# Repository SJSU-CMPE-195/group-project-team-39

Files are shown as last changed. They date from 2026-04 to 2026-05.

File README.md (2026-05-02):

# RoboMallet

Source code for the ROBOTMALLET robotic system's control logic.

## Team

| Name | GitHub | Email |
| --- | --- | --- |
| Kenny Tran | [@ktran1121](https://github.com/ktran1121) | kenny.k.tran@sjsu.edu |
| Kshitij Shirule | [@K-Shirule](https://github.com/K-Shirule) | kshitij.shirule@sjsu.edu |
| Nam Nguyen | [@namng2](https://github.com/namng2) | nam.h.nguyen04@sjsu.edu  |
| Yathien Thai | [@yyaatt0](https://github.com/yyaatt0) | yathien.thai@sjsu.edu |

**Advisor:** [Dr. Wencen Wu]

## Prerequisites

- [Docker Desktop](https://www.docker.com/products/docker-desktop/) installed and running
- A Docker Hub account (required to build and push container images)
- Docker Buildx enabled (included by default in Docker Desktop)
- SSH or terminal access to the target MCU/board ([PuTTY](https://www.putty.org/) recommended for Windows users)

## Installation

1. Clone the repository:

   ```bash
   git clone https://github.com/<your-org>/RoboMallet.git
   cd RoboMallet
   ```

2. Log in to your Docker Hub account:

   ```bash
   docker login -u yathien
   ```

3. Build and push the C++ service container:

   ```bash
   docker buildx build --platform linux/arm64 -t yathien/cppsvc:dev --push ./cppsvc
   ```

4. Build and push the Python service container:

   ```bash
   docker buildx build --platform linux/arm64 -t yathien/pysvc:dev --push ./pysvc
   ```

## Configuration

Before running the application, ensure the following hardware is connected to the MCU:

- Motor drivers (iSV57T) wired to the appropriate GPIO pins for DIR and PUL signals
- Limit switches wired to the designated GPIO input pins
- All power supplies are connected and within operating voltage range

Refer to the Ixora carrier board datasheet and the pin mapping in the project documentation for exact GPIO assignments.

## Running the Application

SSH into the target board and run:

```bash
cd ~/RoboMallet
docker compose pull
docker compose up -d
```

To view logs:

```bash
docker compose logs -f
```

To stop the application:

```bash
docker compose down
```

## Usage

Once the containers are running, the robotic system will initialize the motor drivers and limit switches on startup. The system listens for commands to control mallet rotation and positioning.

## Project Structure

```
RoboMallet/
├── cppsvc/                 # C++ service (motor control, GPIO interface)
│   ├── include/            # Header files (.hpp)
│   ├── src/                # Source files (.cpp)
│   ├── main.cpp            # Entry point
│   ├── Dockerfile          # ARM64 container build
│   └── CMakeLists.txt      # Build configuration
├── pysvc/                  # Python service
│   ├── Dockerfile          # ARM64 container build
│   └── main.py             # Entry point
├── docker-compose.yml      # Multi-container orchestration
└── README.md
```

## Stress Test Results

### Test Configuration
- Testing Type: Playing against robot for stress testing  
- Duration: 10-15 minutes per trial  
- Input Method: Manual puck shots (human player)  
- Scenarios Tested:
  - Straight shots at varying speeds  
  - Angled shots including wall bounces  
  - Rapid consecutive shots (high-frequency gameplay)  
- Environment:
  - Fixed overhead camera  
  - Controlled and Bright indoor lighting for easy color detection

---

### Results
| Metric | Value |
|---|---|
| Max Trackable Puck Speed | 0.813 m/s |
| Interception Success Rate | 93.5 % |
| Avg Response Time (vision → actuation) | 21 - 81 ms |
| Prediction Error (avg) | 15% |

---

### Observations
- System performs reliably for straight and angled shots  
- Performance decreases for high-speed, multi-bounce trajectories, and drift caused due to air
- Largest bottleneck is in the transferance of information from one process to the next using shared memory
- Occasional tracking loss observed during rapid consecutive shots

---

### Bottlenecks
- Camera frame rate and image processing latency  
- Mechanical limits of gantry speed and acceleration  

---

### Testing Approach

| Approach | Tool | Use Case |
|---|---|---|
| Manual Testing | Documented procedure | Simulate real gameplay with controlled shot variations |
| Vision Pipeline Testing | OpenCV (logging + profiling) | Measure detection latency and tracking accuracy using hardware timers and counters |
| Control System Testing | Motor controller + encoder feedback | Evaluate response time and positioning accuracy |
| Integrated System Testing | Full system | End-to-end performance under realistic game conditions |

## Demo

🎥 **Project Demo Videos**

- [CMPE195B RoboMallet Group39 Demo 1](https://youtu.be/watch?v=AesrC-o85-U)
- [CMPE195B RoboMallet Group39 Demo 2](https://youtu.be/WAsmsQb9nug)

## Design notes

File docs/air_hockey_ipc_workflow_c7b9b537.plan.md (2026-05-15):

---
name: Air Hockey IPC Workflow
overview: Integrate pysvc (object detection) and cppsvc (gantry control) via POSIX shared memory and semaphores, with a new trajectory predictor, coordinate mapper, and IPC handler classes on both sides. The workflow detects incoming pucks, predicts trajectories with bounce support, checks critical zone intersection, and sends movement commands to the gantry.
todos:
  - id: coord-mapper
    content: "Create pysvc/coordinate_mapper.py: CoordinateMapper class with configurable offsets, pixel<->gantry conversion"
    status: done-deviation
    note: "Folded into px_to_gantry_mm() in pysvc/main.py + constants in calibration_config.py. No separate class."
  - id: puck-detector
    content: "Create pysvc/puck_detector.py: PuckDetector class wrapping detection + tracking (green_mask_hsv, detect_green_puck_center, p0/p1 state, missing_count)"
    status: done-deviation
    note: "Detection lives in pysvc/green_puck_detect.py (functions, not a class). Kalman tracking + missing_count state is inline in pysvc/main.py."
  - id: trajectory-predictor
    content: "Create pysvc/trajectory_predictor.py: TrajectoryPredictor class with bounce-aware ray casting and critical zone intersection test"
    status: done-deviation
    note: "Implemented inline as trace_path_to_bottom() + first_border_intersection() in pysvc/main.py. Approach differs from plan: cast to bottom row and check predicted X (instead of per-segment ray-vs-rect)."
  - id: py-ipc
    content: "Create pysvc/ipc_handler.py: IPCHandler class using posix_ipc for shared memory + semaphores (send_command, read_status, close)"
    status: completed
  - id: cpp-ipc
    content: "Create cppsvc/include/ipc_handler.hpp + cppsvc/src/ipc_handler.cpp: AirHockeyIPC struct, IPCHandler class (read_command, write_status, wait_for_command)"
    status: completed
  - id: py-main
    content: "Modify pysvc/main.py: comment out old code, add new main loop integrating PuckDetector + TrajectoryPredictor + CoordinateMapper + IPCHandler"
    status: in-progress
    note: "Main loop, detection, tracking, and INTERCEPT/IDLE commands are wired. STILL-puck PUSH_NORTH / PUSH_OUT branches (workflow steps 3e Case 1 & 2) are NOT yet implemented."
  - id: cpp-main
    content: "Modify cppsvc/main.cpp: add IPC command loop (home -> default pos -> wait for command -> move_to_coord -> update status)"
    status: completed
  - id: cmake
    content: "Modify cppsvc/CMakeLists.txt: add ipc_handler.cpp source, link rt library"
    status: completed
  - id: push-emit
    content: "Wire PUSH_NORTH / PUSH_OUT two-step sequences into pysvc/main.py per workflow step 3e and Edge Cases 1 & 2 (position behind puck, wait ready=1, send target_y=901)."
    status: pending
    note: "Agreed BEHIND_OFFSET_MM = 80 (mallet r ~47.5mm + puck r ~30mm). If puck stops being STILL between step 1 and step 2, abort sequence and re-evaluate next tick."
  - id: low-light-hardening
    content: "Low-light robustness: CLAHE on V channel in green_mask_hsv(); Kalman processNoiseCov velocity terms lowered to 1e-3, measurementNoiseCov raised to 1e-1; dev HUD shows |v| and still_count under HEADLESS=0."
    status: completed
  - id: calib-assert
    content: "verify_gantry_calibration() in pysvc/main.py asserts GANTRY_TL_PX -> (0,901) mm and GANTRY_BR_PX -> (869,0) mm within CALIBRATION_TOL_MM (2.0). px_to_gantry_mm_raw() helper added so the clamp doesn't mask errors. crop_calibrate.py PREVIEW shows live implied mm with OK/BAD tags + loud warning on S-save."
    status: completed
    note: "Bypass via SKIP_CALIBRATION_CHECK=1 env var. Current calibration_config.py values FAIL the check (PX_PER_CM_X derived from 55cm CRIT zone vs GANTRY implying ~3.87 px/cm) -- rig re-calibration required."
  - id: corner-check
    content: "run_four_corner_check() in pysvc/main.py drives the gantry to SW(0,0), SE(869,0), NE(869,901), NW(0,901) via INTERCEPT, waits ready=1 with status_seq advance + 30s timeout per corner, prompts operator y/n/r, exits non-zero on any fail. Sends IDLE to park afterwards."
    status: completed
    note: "Bypass via SKIP_CORNER_CHECK=1 env var. Runs after IPC connect, before camera loop."
isProject: false
---

# Air Hockey IPC Workflow Plan

## Implementation status (snapshot)

This plan was written as the design doc for the pysvc ↔ cppsvc IPC integration.
Most of it is now built, with some deviations from the original architecture.
See per-todo `note:` fields in the frontmatter for specifics.

**Done:**

- IPC layer on both sides ([`pysvc/ipc_handler.py`](../pysvc/ipc_handler.py),
  [`cppsvc/include/ipc_handler.hpp`](../cppsvc/include/ipc_handler.hpp),
  [`cppsvc/src/ipc_handler.cpp`](../cppsvc/src/ipc_handler.cpp)).
- cppsvc command loop ([`cppsvc/main.cpp`](../cppsvc/main.cpp)): home → default
  pos → wait → `move_to_coord` → status update.
- CMake wiring (`ipc_handler.cpp` + `rt` link).
- pysvc main loop ([`pysvc/main.py`](../pysvc/main.py)): capture → TPS remap →
  Kalman detection → trajectory prediction → convergence buffer → INTERCEPT /
  IDLE commands.
- Low-light hardening: CLAHE V-channel normalisation in `green_mask_hsv()`,
  retuned Kalman covariance (`processNoiseCov` velocity terms = `1e-3`,
  `measurementNoiseCov` = `1e-1`), and a `HEADLESS=0` dev HUD showing
  `|v|` and `still_count`.
- Calibration verification: `verify_gantry_calibration()` asserts the
  GANTRY pixel-corner → mm mapping at pysvc startup;
  `run_four_corner_check()` drives the gantry to the four mm corners and
  prompts the operator to confirm each.  `SKIP_CALIBRATION_CHECK=1` and
  `SKIP_CORNER_CHECK=1` env vars bypass.  See
  [`docs/handoff.md`](handoff.md) → *Calibration verification* for the
  full design.

**Not yet built:**

- `PUSH_NORTH` / `PUSH_OUT` emit logic in pysvc (workflow step 3e, Cases 1 & 2).
  Defined in the IPC protocol and described in *Edge Case Handling* below,
  but `main.py` only emits `IDLE` and `INTERCEPT` today.

**Deviations from this plan:**

- No separate `CoordinateMapper`, `PuckDetector`, `TrajectoryPredictor`
  classes. The functionality is split between
  [`pysvc/green_puck_detect.py`](../pysvc/green_puck_detect.py) (HSV +
  centroid) and inline helpers in `main.py` (`px_to_gantry_mm`,
  `trace_path_to_bottom`, `first_border_intersection`). Calibration
  constants live in
  [`pysvc/calibration_config.py`](../pysvc/calibration_config.py) instead of
  being class fields.
- Trajectory prediction casts to the bottom row (robot side) and checks
  the predicted X against the critical-zone X-range, plus a convergence
  buffer for stability. The plan's per-segment ray-vs-rectangle test
  was not implemented — current approach is simpler and good enough for
  INTERCEPT, but it ignores trajectories that *enter* the critical zone
  laterally without reaching the bottom row.
- `pysvc/calibration_config.py` adds `PLAY_*_PX` and `GANTRY_*_PX` nested
  rectangles (a refinement not in the original plan) so `main.py` can
  branch on which region a STILL puck is in. See
  [`docs/handoff.md`](handoff.md) → *Camera physical coverage*.

For the canonical state-of-the-system overview, see
[`docs/handoff.md`](handoff.md).

---

## Coordinate System

Both services will use a **bottom-left origin** with X right, Y up:

- **Camera pixel space**: (0,0) at bottom-left, (640, 360) at top-right. OpenCV natively uses top-left origin, so all Y values are flipped via `y_cam = (h - 1) - y_opencv`.
- **Gantry space**: (0,0) at bottom-left (south-west, limit switch corner), (869, 901) mm at top-right. Already matches after homing.

### Pixel-to-Gantry Mapping ([`pysvc/coordinate_mapper.py`](pysvc/coordinate_mapper.py) -- new file)

The camera view physically covers a larger area than the gantry range, with configurable offsets:

```
Camera physical extent:
  width  = LEFT_OFFSET + GANTRY_X + RIGHT_OFFSET = 55 + 869 + 55 = 979 mm
  height = BOTTOM_OFFSET + GANTRY_Y + TOP_OFFSET  = 47 + 901 + 0  = 948 mm

Conversion (camera pixel -> gantry mm):
  x_mm = (pixel_x / CAM_WIDTH) * PHYS_WIDTH - LEFT_OFFSET
  y_mm = (pixel_y / CAM_HEIGHT) * PHYS_HEIGHT - BOTTOM_OFFSET

Valid gantry range: 0 <= x_mm <= 869, 0 <= y_mm <= 901
```

All offsets (`LEFT_OFFSET_MM`, `RIGHT_OFFSET_MM`, `BOTTOM_OFFSET_MM`, `TOP_OFFSET_MM`) and camera resolution (`CAM_WIDTH`, `CAM_HEIGHT`) are configurable constants.

The `CoordinateMapper` class provides:

- `pixel_to_gantry_mm(px, py) -> (x_mm, y_mm)` -- converts and returns raw mm (can be outside gantry range)
- `gantry_mm_to_pixel(x_mm, y_mm) -> (px, py)` -- inverse
- `is_in_gantry_range(x_mm, y_mm) -> bool` -- bounds check
- `clamp_to_gantry(x_mm, y_mm) -> (x_mm, y_mm)` -- clamp to nearest valid gantry position

---

## Critical Zone

Defined in **camera pixel space** (bottom-left origin) as a configurable rectangle. Default: full width, from Y=0 to `CRITICAL_ZONE_Y_MAX` (configurable, e.g. 180 px = bottom half). Any predicted trajectory that enters this rectangle triggers a gantry INTERCEPT command.

---

## Files (as built)

The architecture in *Implementation status* above differs from the original
plan (no separate detector / predictor / mapper classes).  Below is what
actually got built.

### pysvc (Python) — created

| File | Status | Purpose |
| ---- | --- | --- |
| [`pysvc/ipc_handler.py`](../pysvc/ipc_handler.py) | done | `IPCHandler` class: posix_ipc shared memory + semaphores (`send_command`, `read_status`, `close`). |
| [`pysvc/green_puck_detect.py`](../pysvc/green_puck_detect.py) | done | `green_mask_hsv()` (CLAHE + HSV inRange + morph) and `detect_green_puck_center()` (contour centroid). Replaces the planned `PuckDetector` class. |
| [`pysvc/vision_preprocess.py`](../pysvc/vision_preprocess.py) | done | `build_remap_maps()` (TPS RBF) + `preprocess_frame()` (remap → 90-CW rotate). Shared by `main.py`, `test_detection.py`, `crop_calibrate.py`. |
| [`pysvc/calibration_config.py`](../pysvc/calibration_config.py)| done | Single source for `OUTPUT_W/H`, `SRC_POINTS`, `MALLET_ORIGIN_PX`, `PLAY/GANTRY/CRIT` nested rectangles, `PX_PER_CM_X/Y`. Replaces the planned `CoordinateMapper` configurable constants. |
| [`pysvc/camera.py`](../pysvc/camera.py) | done | `StereoCamera` wrapper around V4L2 + per-pixel stereo fusion. |
| [`pysvc/crop_calibrate.py`](../pysvc/crop_calibrate.py) | done | One-time GUI tool: drag TPS handles + PLAY/GANTRY/CRIT/MALLET handles, prints config block on **S**. |
| [`pysvc/test_detection.py`](../pysvc/test_detection.py) | done | Visual detector test (no IPC, no Kalman). Same remap + HSV path as `main.py`. |

### pysvc (Python) — NOT created (folded inline)

| Planned file | Where it lives now |
| --- | --- |
| `pysvc/puck_detector.py` (PuckDetector class) | Detection in `green_puck_detect.py`; Kalman + tracking state inline in `main.py`. |
| `pysvc/trajectory_predictor.py` (TrajectoryPredictor) | `trace_path_to_bottom()` + `first_border_intersection()` inline in `main.py`. |
| `pysvc/coordinate_mapper.py` (CoordinateMapper class) | `px_to_gantry_mm()` inline in `main.py`; constants in `calibration_config.py`. |

### cppsvc (C++) — created

| File | Status | Purpose |
| ---- | --- | --- |
| [`cppsvc/include/ipc_handler.hpp`](../cppsvc/include/ipc_handler.hpp) | done | `IPCHandler` class header + `AirHockeyIPC` struct + `static_assert(sizeof == 32)`. |
| [`cppsvc/src/ipc_handler.cpp`](../cppsvc/src/ipc_handler.cpp) | done | shm_open + sem_open setup, read commands, write status. |

### Modified files

| File | Status |
| ---- | --- |
| [`pysvc/main.py`](../pysvc/main.py) | Capture → TPS remap → Kalman detection → trajectory → convergence-based commit → INTERCEPT / IDLE. PUSH branches still pending. |
| [`cppsvc/main.cpp`](../cppsvc/main.cpp) | done — home → default pos → wait for command → `move_to_coord` → status update. |
| [`cppsvc/CMakeLists.txt`](../cppsvc/CMakeLists.txt) | done — `ipc_handler.cpp` added, `rt` linked. |

`objectdetect_and_trajectory.py` and `object_detect_Apalis.py` remain as-is (legacy reference).

---

## Shared Memory Layout

Named shared memory: `/airhockey_shm`

```
struct AirHockeyIPC {
    // Command (pysvc -> cppsvc)
    float    target_x_mm;     // gantry target X
    float    target_y_mm;     // gantry target Y
    uint8_t  command;          // IDLE=0, INTERCEPT=1, PUSH_NORTH=2, PUSH_OUT=3
    uint8_t  priority;         // LOW=0, MEDIUM=1, HIGH=2
    uint16_t _pad1;
    uint32_t command_seq;      // incremented per new command

    // Status (cppsvc -> pysvc)
    float    current_x_mm;    // current mallet X
    float    current_y_mm;    // current mallet Y
    uint8_t  state;            // IDLE=0, MOVING=1, HOMING=2, ERROR=3
    uint8_t  ready;            // 1 = ready for next command
    uint16_t _pad2;
    uint32_t status_seq;       // incremented per status update
};
// Total: 32 bytes, naturally aligned
```

Priority mapping: INTERCEPT=HIGH(2), PUSH_NORTH=MEDIUM(1), PUSH_OUT=MEDIUM(1), IDLE=LOW(0).

---

## Semaphore Protocol

Two named POSIX semaphores:

- **`/airhockey_mutex`** (binary, init=1): Protects shared memory reads/writes.
- **`/airhockey_cmd`** (counting, init=0): Signals cppsvc that a new command is available.

### Write sequence (pysvc):

1. `sem_wait(mutex)` -- acquire lock
2. Write command fields to shared memory, increment `command_seq`
3. `sem_post(mutex)` -- release lock
4. `sem_post(cmd)` -- signal cppsvc

### Read sequence (cppsvc):

1. `sem_wait(cmd)` -- block until command available
2. `sem_wait(mutex)` -- acquire lock
3. Read command fields, copy locally
4. `sem_post(mutex)` -- release lock
5. Execute movement

### Status update (cppsvc):

1. `sem_wait(mutex)` -- acquire lock
2. Write status fields, increment `status_seq`
3. `sem_post(mutex)` -- release lock

### Status read (pysvc):

1. `sem_wait(mutex)` -- acquire lock
2. Read status fields
3. `sem_post(mutex)` -- release lock

---

## Workflow: pysvc Main Loop

```
1. Initialize: PuckDetector, TrajectoryPredictor, CoordinateMapper, IPCHandler
2. Open camera (configurable resolution/fps)
3. Loop:
   a. Read frame
   b. puck_state = detector.update(frame)   # returns position, velocity, is_still, is_detected
   c. Flip Y for bottom-left origin
   d. If NOT detected:
        - Send IDLE command (gantry returns to default position)
        - continue
   e. If puck is STILL:
        - Convert puck position to gantry mm
        - Case 1: Puck is on the side, outside gantry X range (x_mm < 0 or x_mm > 869)
            -> Send PUSH_NORTH: target_x = clamp(x_mm, 0, 869), target_y = 901 (push to top)
        - Case 2: Puck is within gantry range but outside critical zone
            -> Send PUSH_OUT: target = position behind puck, then push north
        - Case 3: Puck is in critical zone (do nothing special, it's on our side and still)
            -> Send IDLE or hold position
   f. If puck is MOVING:
        - predicted_pt = trajectory.predict(puck_pos, velocity, camera_bounds)
          (handles side-wall bounces, returns predicted endpoint)
        - Check if predicted trajectory intersects critical zone
        - If YES:
            -> Convert intersection point to gantry mm
            -> Clamp to gantry range
            -> Send INTERCEPT command (priority=HIGH)
        - If NO:
            -> Send IDLE (puck heading away from us)
   g. Read cppsvc status for logging/monitoring
```

---

## Workflow: cppsvc Main Loop

```
1. Initialize: gantry (motors, switches), IPCHandler
2. Home gantry: move_to_origin()
3. Move to default position: move_to_coord(434, 0)  // center-bottom
4. Update status: state=IDLE, ready=1
5. Loop:
   a. Wait for command (sem_wait on /airhockey_cmd)
   b. Read command from shared memory
   c. Update status: state=MOVING, ready=0
   d. Execute: move_to_coord(target_x_mm, target_y_mm)
   e. Update status: current_x/y = new position, state=IDLE, ready=1
   f. Loop back to (a)
```

For PUSH commands, the gantry moves to the target position which is pre-calculated by pysvc to be "behind" the puck, then pysvc sends a follow-up coordinate to push through.

---

## Edge Case Handling

### Edge Case 1: Puck at rest on the side, outside gantry X range

The puck is in the 5.5cm offset zone (camera sees it, but gantry can't reach its exact X). The mallet moves to the nearest gantry edge at the puck's Y coordinate minus an offset (to get "behind" it), then pushes north. Since the mallet is at the gantry edge and the puck is just outside, the mallet "rubs against the side" of the puck, pushing it northward out of the camera view.

**pysvc logic:**

1. Detect puck is still and `x_mm < 0` or `x_mm > 869`
2. Set `target_x = 0` (if puck on left side) or `target_x = 869` (if puck on right side)
3. Set `target_y = puck_y_mm - BEHIND_OFFSET` (position behind/south of puck)
4. Send PUSH_NORTH command
5. After gantry reports ready, send follow-up with `target_y = 901` (push north to max)

### Edge Case 2: Puck at rest outside critical zone, within gantry range

The puck is reachable by the gantry but not in the critical zone (it's in the upper portion of the field). Push it north out of the camera view.

**pysvc logic:**

1. Detect puck is still and within gantry range but Y > critical zone top
2. Set `target_x = puck_x_mm`, `target_y = puck_y_mm - BEHIND_OFFSET`
3. Send PUSH_OUT command
4. After gantry reports ready, send follow-up with `target_y = 901` (push north to camera edge)

### Edge Case 3: No puck detected

Send IDLE -- gantry returns to default position (center-bottom: 434, 0).

---

## Trajectory Prediction ([`pysvc/trajectory_predictor.py`](pysvc/trajectory_predictor.py))

New prediction logic with bounce support:

1. From puck position and velocity direction, cast a ray
2. Find first intersection with camera boundary (left, right, top, bottom walls)
3. If hits a **side wall** (left/right): reflect velocity, continue ray from bounce point
4. Repeat for up to `MAX_BOUNCES` (configurable, default 3)
5. At each step, check if the ray segment passes through the critical zone rectangle
6. If any segment enters the critical zone, return the intersection point with the critical zone boundary as the target
7. If the trajectory exits the camera view (hits top wall = opponent's side) without entering the critical zone, return None (no threat)

The critical zone intersection test is a ray-vs-rectangle intersection: check if the ray segment from point A to point B crosses into the rectangle defined by `(0, 0)` to `(CAM_WIDTH, CRITICAL_ZONE_Y_MAX)`.

---

## Dependencies

**pysvc**: `posix_ipc>=1.1.0` (already in `requirements-ipc.txt`), `opencv-python-headless`, `numpy`

**cppsvc**: `libgpiod`, `pthread`, `rt` (for `shm_open`/`sem_open` -- POSIX realtime extensions)

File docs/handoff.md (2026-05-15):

# Air Hockey Project -- Agent Handoff

This document captures the current state of the air hockey robot project so the
next contributor can pick it up without reading the full chat history.

---

## System overview

Two services talk over POSIX shared memory + named semaphores:

```
ZED 2i camera --> pysvc (Python, vision + game logic) ---- /airhockey_shm ----> cppsvc (C++, gantry motor control)
                                                            /airhockey_cmd
                                                            /airhockey_mutex
```

- **pysvc** runs on a Torizon Linux container, captures frames from the ZED 2i
  via V4L2, fuses both stereo eyes into one image, applies a TPS remap to
  correct perspective distortion, detects the green puck with a Kalman filter,
  predicts its trajectory using bounce-aware ray casting, and sends intercept
  coordinates over shared memory when the puck is heading into the critical zone.
- **cppsvc** runs on a separate container with GPIO access, drives two iSV57T
  BLDC motors in CoreXY configuration, reads two limit switches for homing,
  and consumes commands from shared memory one at a time.

Hardware target: **Toradex Apalis iMX8** (NXP i.MX8) on an Ixora carrier board.

---

## Repository layout

```
group-project-team-39/
├── pysvc/                       # Python vision service
│   ├── main.py                  # main loop: capture -> remap -> detect -> predict -> command
│   ├── calibration_config.py   # OUTPUT_W/H, SRC_POINTS, mallet origin, PLAY/GANTRY/CRIT rectangles, px/cm (single source)
│   ├── vision_preprocess.py    # TPS remap build + preprocess_frame (shared with test tool)
│   ├── green_puck_detect.py    # HSV green puck centroid (shared with test tool)
│   ├── camera.py                # ZED 2i V4L2 capture wrapper (stereo fusion)
│   ├── ipc_handler.py           # posix_ipc shm + semaphores (writer side)
│   ├── crop_calibrate.py        # one-time tool: calibrate TPS remap + critical zone
│   ├── test_detection.py        # visual test: same remap + detection as main (no IPC)
│   ├── requirements-ipc.txt     # posix_ipc, scipy; cv2/numpy come from Dockerfile
│   └── Dockerfile
├── cppsvc/                      # C++ gantry control service
│   ├── main.cpp                 # init hardware -> home -> IPC command loop
│   ├── CMakeLists.txt
│   ├── docker-compose.yml       # both services + m4loader
│   ├── include/
│   │   ├── gantry.hpp           # CoreXY gantry interface
│   │   ├── iSV57T.hpp           # motor driver
│   │   ├── limitSwitch.hpp      # GPIO limit switch reader
│   │   └── ipc_handler.hpp      # AirHockeyIPC struct + IPCHandler (reader)
│   └── src/                     # implementations of the above
├── docs/                        # this folder
└── stl_designs/                 # mechanical CAD
```

---

## Coordinate systems

All gameplay logic uses a **bottom-left origin** (X right, Y up):

- **Portrait pixel space** (after TPS remap + 90-CW rotation): (0,0) at
  top-left in OpenCV convention, but `MALLET_ORIGIN_PX` marks where gantry
  (0,0) appears in that frame.  `px_to_gantry_mm()` in `main.py` converts
  from pixel coordinates to absolute gantry mm using `MALLET_ORIGIN_PX` and
  `PX_PER_CM_X`/`PX_PER_CM_Y` (values live in [`calibration_config.py`](../pysvc/calibration_config.py), updated from `crop_calibrate.py`).
- **Gantry space**: (0,0) at the south-west limit-switch corner,
  (869, 901) mm at the north-east. Defined in
  [`cppsvc/include/gantry.hpp`](../cppsvc/include/gantry.hpp).

### Camera physical coverage

The camera is mounted so it sees a **larger area than the gantry can reach**.
Approximate physical extents (per the workflow plan):

```
                  TOP_OFFSET    =   0 mm
                ┌───────────────────────────────┐
                │                               │
LEFT_OFFSET     │      GANTRY_X = 869 mm        │   RIGHT_OFFSET
   = 55 mm      │      GANTRY_Y = 901 mm        │      = 55 mm
                │                               │
                └───────────────────────────────┘
                  BOTTOM_OFFSET = 47 mm

Camera total: 979 × 948 mm  (gantry sits inside, ~5.5 cm slack on each side)
```

Those 5.5 cm side strips are what enable **PUSH_NORTH** (edge case 1 in
*Edge cases*): the puck can rest in a region the camera sees but the gantry
cannot reach in X.  The play-area / gantry-range / critical-zone rectangles
defined in [`calibration_config.py`](../pysvc/calibration_config.py)
(`PLAY_*_PX`, `GANTRY_*_PX`, `CRIT_*_PX`) encode this nesting in pixel
space so `main.py` can branch on which region the puck currently sits in.

---

## IPC protocol

### Shared memory (`/airhockey_shm`, 32 bytes)

| Offset | Field | Type | Direction |
| -----: | --- | --- | --- |
| 0 | `target_x_mm`  | float | py -> cpp |
| 4 | `target_y_mm`  | float | py -> cpp |
| 8 | `command` | uint8 | py -> cpp |
| 9 | `priority` | uint8 | py -> cpp |
| 12 | `command_seq`  | uint32 | py -> cpp |
| 16 | `current_x_mm` | float | cpp -> py |
| 20 | `current_y_mm` | float | cpp -> py |
| 24 | `state` | uint8 | cpp -> py |
| 25 | `ready` | uint8 | cpp -> py |
| 28 | `status_seq` | uint32 | cpp -> py |

The byte layout is also documented at the top of
[`pysvc/ipc_handler.py`](../pysvc/ipc_handler.py) and
[`cppsvc/include/ipc_handler.hpp`](../cppsvc/include/ipc_handler.hpp).
A `static_assert(sizeof(AirHockeyIPC) == 32)` in the C++ header guards against
accidental padding drift; the Python `struct` format `=ffBBHIffBBHI` matches.

### Semaphores

- `/airhockey_mutex` -- binary, init=1, protects shm reads/writes
- `/airhockey_cmd`   -- counting, init=0, posted by pysvc when a new command
  is ready, awaited by cppsvc before reading

### Command values

```
IDLE=0  INTERCEPT=1  PUSH_NORTH=2  PUSH_OUT=3
```

Priority mapping: `INTERCEPT` = HIGH (2), `PUSH_NORTH`/`PUSH_OUT` = MEDIUM (1),
`IDLE` = LOW (0).  Priority is informational today — cppsvc processes commands
strictly in FIFO order (see *Execution model* below).

**Implementation status:** the IPC layer (both sides) and the cppsvc command
loop support all four commands.  In `pysvc/main.py`, only `IDLE` and
`INTERCEPT` are emitted today; the `PUSH_NORTH` / `PUSH_OUT` branches are
specified by the workflow plan ([`docs/air_hockey_ipc_workflow_c7b9b537.plan.md`](air_hockey_ipc_workflow_c7b9b537.plan.md))
and described in *Edge cases* below but not yet wired into the vision loop.

### Execution model (important)

**cppsvc is strictly sequential**: it `sem_wait`s for one command, runs the
full blocking `move_to_coord`, marks `ready=1`, then waits for the next.
There is no preemption or mid-motion update.

### Status feedback (cpp -> py)

Every state transition in cppsvc (HOMING, MOVING, IDLE, ERROR) is written
back to shared memory under `mutex`, with `current_x_mm`, `current_y_mm`,
and a monotonic `status_seq`.  pysvc can read this back at any time via
`IPCHandler.read_status()` — used today for logging, and required by the
PUSH two-step sequences (see *Edge cases*), which wait on `ready == 1`
before sending the follow-up `target_y = 901` command.

---

## pysvc main loop logic

State machine inside [`pysvc/main.py`](../pysvc/main.py):

### Frame preprocessing

1. ZED 2i outputs a 2560×720 side-by-side stereo frame at 60 FPS.
2. Both eyes (each 1280×720) are **pixel-averaged** (fused) into a single
   1280×720 image -- reduces noise compared to using one eye alone.
3. A **Thin-Plate-Spline (TPS) remap** corrects perspective distortion, warping
   the fused image onto a flat OUTPUT_W×OUTPUT_H (510×400) canvas aligned to
   the table edges.
4. A **90-CW rotation** produces a 400×510 portrait frame where the robot
   side is at the bottom (row h-1) and the opponent side is at the top (row 0).

### Detection & tracking

A **Kalman filter** (constant-velocity, 4-state [x, y, vx, vy]) tracks the
green puck across frames.  HSV masking + contour detection provides raw
measurements; a jump-gate rejects outlier detections.

**Low-light hardening (in place):**

- `green_mask_hsv()` in [`pysvc/green_puck_detect.py`](../pysvc/green_puck_detect.py)
  runs **CLAHE** (`clipLimit=2.0, tileGridSize=(8,8)`) on the V channel
  before `cv2.inRange`, so dim frames are histogram-normalised and the
  HSV bounds (`H:[25,95] S/V:[40,255]`) still match.
- `create_kalman()` in [`pysvc/main.py`](../pysvc/main.py) uses
  `processNoiseCov` diag `[1e-2, 1e-2, 1e-3, 1e-3]` and
  `measurementNoiseCov = 1e-1 * I`.  The low velocity-process-noise
  suppresses centroid jitter under poor lighting from being interpreted
  as real velocity, which kept the puck oscillating STILL ↔ MOVING.
  If a real fast shot ever feels sluggish, raise velocity terms back
  toward `1e-2` or drop `measurementNoiseCov` to `5e-2`.
- A debug HUD (`|v|=X.Xpx  still=N  STILL/MOVING`) prints under the FPS
  line when `HEADLESS=0`.  Use it to visually confirm the filter is
  settling under whatever lighting you're tuning.

### Trajectory prediction

When the Kalman-filtered speed exceeds `MIN_SPEED_PX`:
- `trace_path_to_bottom()` casts a bounce-aware ray from the puck's position
  in the direction of its velocity, reflecting off left/right walls, until
  it reaches the bottom row (robot side) or exceeds `MAX_BOUNCES`.
- The predicted bottom-target X is accumulated in a time-windowed
  **prediction buffer**.

### Command decision

The state machine picks an IPC command each evaluation tick, based on whether
the puck is detected and whether it is moving (Kalman `|v|` thresholded by
`STILL_THRESH_PX` for `STILL_CONFIRM_FRAMES` consecutive frames):

```
no puck detected            -> IDLE
puck STILL, outside gantry X-> PUSH_NORTH  (edge case 1, two-step)
puck STILL, inside gantry,
       outside critical zone-> PUSH_OUT    (edge case 2, two-step)
puck STILL, inside critical -> IDLE / hold position
puck MOVING:
   trace_path_to_bottom + convergence buffer:
      predicted X in critical zone -> INTERCEPT
      otherwise                    -> IDLE
```

**Convergence-based commit (INTERCEPT path):**

- The most recent `RECENT_N` buffer samples are checked for spread ≤
  `CONVERGE_SPREAD_PX`.  Only converged predictions are acted on.
- **In critical zone** (target X inside `CRIT_TL_PX[0]`..`CRIT_BR_PX[0]`):
  send `INTERCEPT` at the predicted gantry mm coordinate.
- **Outside critical zone**: send `IDLE` (gantry returns to default position).
- An **anchor/refine deadband** (`ANCHOR_DEADBAND_PX` / `REFINE_DEADBAND_PX`)
  prevents oscillation: once an INTERCEPT is committed, small jitter in the
  predicted target is ignored until the prediction shifts by ≥ 30 px.
- When the buffer empties (puck slows or disappears): send `IDLE`.

### Edge cases (PUSH sequences)

Both PUSH cases are **two-step sequences** emitted by pysvc.  cppsvc itself
makes no distinction between PUSH and INTERCEPT — it just runs
`move_to_coord` to the supplied target — so the "position behind, then
shove north" feel is enforced entirely by pysvc sending two sequenced
commands and waiting on `ready=1` between them.

**Edge case 1 — puck at rest just outside the gantry's X range** (the
~5.5 cm camera-edge zone where the camera sees the puck but the gantry can
not reach its exact X):

1. Send `PUSH_NORTH` with `target_x = 0` (puck on left side) or
   `target_x = 869` (puck on right side), `target_y = puck_y_mm - BEHIND_OFFSET`.
   The mallet positions at the gantry edge, south of the puck.
2. Wait for cppsvc `ready = 1`, then send a follow-up command with
   `target_y = 901` — the mallet rubs against the side of the puck and
   pushes it north out of the camera view.

**Edge case 2 — puck at rest within gantry range, above the critical zone**:

1. Send `PUSH_OUT` with `target_x = puck_x_mm`,
   `target_y = puck_y_mm - BEHIND_OFFSET`.  Mallet positions directly
   south of the puck.
2. Wait for cppsvc `ready = 1`, then send `target_y = 901`.

**Edge case 3 — no puck detected**: send `IDLE` — gantry returns to its
default rest position `(DEFAULT_X_MM, DEFAULT_Y_MM)` = `(434, 0)` mm.

---

## Camera setup

The ZED 2i outputs a side-by-side V4L2 frame at 720p mode
(2560×720 @ 60 FPS).  Both eyes are averaged per-pixel to produce a single
1280×720 fused frame.

[`pysvc/camera.py`](../pysvc/camera.py) contains the `StereoCamera` class.

### One-time TPS calibration

Run on a machine with a display attached and the ZED plugged in:

```bash
cd pysvc
python crop_calibrate.py
```

Two windows open:

**RAW window** -- drag the 6 teal handles wider than the playing surface
(include table rails / margin).  The puck gets clipped at the south edge
if you crop flush with the play area.

**PREVIEW window** -- the TPS-remapped + 90-CW-rotated view.  Four nested
regions, each with two draggable corner handles (inner handles are hard-
clamped to stay inside their parent):

| Handle colour | Region | What to drag it to |
| --- | --- | --- |
| Green  | `PLAY` | Actual playing-surface edges |
| Yellow | `GANTRY` | Gantry's reachable rectangle |
| Blue | `CRIT` | Physical critical zone (55 cm × 35 cm) |
| Orange | `MALLET 0,0` | Where the gantry sits at (0, 0) |

Press **S** to print the config block.  Paste all printed values into
[`pysvc/calibration_config.py`](../pysvc/calibration_config.py) (overwrite
`OUTPUT_W`, `OUTPUT_H`, `SRC_POINTS`, `MALLET_ORIGIN_PX`,
`PLAY_TL_PX`, `PLAY_BR_PX`, `GANTRY_TL_PX`, `GANTRY_BR_PX`,
`CRIT_TL_PX`, `CRIT_BR_PX`, `PX_PER_CM_X`, `PX_PER_CM_Y`).
`main.py` and `test_detection.py` import from that file, so they stay aligned.

To verify detection on the same calibrated view before deploying:

```bash
python test_detection.py
```

### Current calibration values ([`pysvc/calibration_config.py`](../pysvc/calibration_config.py))

```python
# Output dimensions of the TPS-remapped frame (pre-rotation, landscape).
OUTPUT_W, OUTPUT_H = 510, 400

SRC_POINTS = [
    (223.0,   7.0),   # TL
    (639.0,   2.0),   # T-mid
    (975.0,   5.0),   # TR
    (975.0, 714.0),   # BR
    (636.0, 719.0),   # B-mid
    (239.0, 715.0),   # BL
]

# Remapped + 90-CW rotated pixel space (portrait, goal at bottom row).
# Nesting: full preview (TPS crop) ⊇ PLAY ⊇ GANTRY ⊇ CRIT.
# Mallet origin lives inside the gantry rectangle.
MALLET_ORIGIN_PX = (195, 403)

PLAY_TL_PX   = (8,  33)
PLAY_BR_PX   = (398, 472)

GANTRY_TL_PX = (30,  33)
GANTRY_BR_PX = (366, 433)

CRIT_TL_PX   = (30,  348)
CRIT_BR_PX   = (366, 433)

PX_PER_CM_X = 6.1091
PX_PER_CM_Y = 2.4286
```

> **Note:** these values were last set by running `crop_calibrate.py` on
> the rig.  Re-run whenever the camera mount or table position changes.

---

## Running

### Local Python (development)

```bash
pip install opencv-python-headless numpy scipy posix_ipc
python crop_calibrate.py   # calibrate first -> paste into calibration_config.py
python main.py             # start vision loop
```

Set `HEADLESS=1` to suppress the OpenCV display window (required in production
containers that have no display):

```bash
HEADLESS=1 python main.py
```

### On the Apalis (production)

`docker compose up` from `cppsvc/` brings up all three services:
`m4loader` (runs once to load M4 firmware), then `cppsvc` and `pysvc` in
parallel. Both have `ipc: host` so they share the POSIX namespaces.

The image names (`yathien/cppsvc:dev`, `yathien/pysvc:dev`) are hardcoded
and need to be built+pushed manually right now.

### Build / runtime dependencies

**pysvc** (Python): `posix_ipc >= 1.1.0` (in
[`requirements-ipc.txt`](../pysvc/requirements-ipc.txt)), `scipy` (for the
TPS RBF interpolator), plus `opencv-python-headless` and `numpy` which come
from the [`Dockerfile`](../pysvc/Dockerfile).

**cppsvc** (C++):
- `libgpiod` — GPIO access for limit switches
- `pthread` — threading primitives
- `rt` — POSIX realtime extensions (`shm_open`, `sem_open`).  Linked in
  [`cppsvc/CMakeLists.txt`](../cppsvc/CMakeLists.txt) so the IPC layer
  works.

---

## Calibration verification (next-up)

Two related tasks that ensure the pixel → mm pipeline actually lands the
gantry where pysvc thinks it will.  Both should be done together — task 1
is a prerequisite for task 2 producing meaningful results.

### Hardware caveat (assumed origin)

`Gantry::move_to_origin()` in cppsvc is **broken on the current hardware**
(limit-switch wiring issue, not a software bug).  Because of this:

- cppsvc's startup currently skips homing.
- The gantry is assumed to be physically parked at the south-west
  limit-switch corner (gantry mm `(0, 0)`) before `cppsvc` is launched.
- `curr_x` / `curr_y` are initialised to `0.0` at the start of
  [`cppsvc/main.cpp`](../cppsvc/main.cpp) and reported through the IPC
  status fields as such.

Anyone running the gantry must manually push the carriage to the SW corner
before `docker compose up`.  Re-enable `move_to_origin()` once the
limit-switch hardware is fixed.

### Task 1: Align the gantry coordinate system across cppsvc and pysvc

`Gantry` in [`cppsvc/include/gantry.hpp`](../cppsvc/include/gantry.hpp)
defines its coordinate frame with the origin at the bottom-left
(south-west, limit-switch corner) and extents `(869, 901)` mm at the
north-east — X grows right, Y grows up.

`GANTRY_TL_PX` and `GANTRY_BR_PX` in
[`calibration_config.py`](../pysvc/calibration_config.py) are the
pixel-space mirror of that rectangle.  In the portrait + bottom-left-origin
frame they must map exactly to:

| Pixel handle | Gantry mm  |
| --- | --- |
| `GANTRY_TL_PX` | `(0, 901)` |
| `GANTRY_BR_PX` | `(869, 0)` |

i.e. `px_to_gantry_mm(*GANTRY_TL_PX)` must return `(0.0, 901.0)` and
`px_to_gantry_mm(*GANTRY_BR_PX)` must return `(869.0, 0.0)`.

**Status: built.** `verify_gantry_calibration()` in
[`pysvc/main.py`](../pysvc/main.py) runs at startup (before the TPS remap
build), using a new unclamped `px_to_gantry_mm_raw()` helper so an
out-of-range pixel maps to out-of-range mm instead of being silently
clipped.  Both corner mm values + deltas are always printed; on any
component exceeding `CALIBRATION_TOL_MM` (default 2.0 mm) the process
exits non-zero.  Set `SKIP_CALIBRATION_CHECK=1` to bypass (dev only).

In [`pysvc/crop_calibrate.py`](../pysvc/crop_calibrate.py), the PREVIEW
window now shows live "GANTRY-TL mm" / "GANTRY-BR mm" readouts with the
expected values and an `OK`/`BAD` tag (BAD lines render in red).  Pressing
**S** still prints the paste block, but prepends a loud `### WARNING ###`
section explaining that pysvc startup will refuse to launch unless both
lines read OK.

> **Heads-up:** the calibration values currently in
> [`calibration_config.py`](../pysvc/calibration_config.py) **fail** this
> assertion — `PX_PER_CM_X = 6.1091` is derived from the 55 cm critical zone
> width but the GANTRY rectangle implies ~3.87 px/cm.  Re-run
> `crop_calibrate.py` on the rig and drag GANTRY / MALLET / CRIT until both
> `GANTRY-TL mm` and `GANTRY-BR mm` lines read OK.

### Task 2: Four-corner movement verification

After task 1 passes, validate end-to-end that the gantry physically reaches
the four corners pysvc commands.  Runs **before** the main vision loop.

**Status: built.** `run_four_corner_check()` in
[`pysvc/main.py`](../pysvc/main.py) executes after `IPCHandler` connect
and before the vision loop.  For each of `SW (0,0)`, `SE (869,0)`,
`NE (869,901)`, `NW (0,901)`:

1. Capture the pre-send `status_seq`.
2. Send `INTERCEPT` to the corner.
3. Poll `read_status()` until `ready == 1` AND `status_seq > pre_seq`
   (so a stale `ready=1` from the previous command doesn't false-pass).
   Per-corner timeout: `CORNER_CHECK_TIMEOUT_S` (default 30 s) → marked
   FAIL on timeout.
4. Operator prompt on stdin:
   `[CORNER] SW: did the gantry reach (0, 0) mm? (y/n/r=retry):`
   - **y** → record success, advance.
   - **n** → record failure, advance.
   - **r** → resend the same coordinate, re-prompt.

After all four, prints a summary table and returns `True` only if every
corner was `y`; main.py exits non-zero otherwise.  On exit (success or
fail) the function sends an `IDLE` to park the gantry at
`(DEFAULT_X_MM, DEFAULT_Y_MM)`.

**Bypass:** `SKIP_CORNER_CHECK=1` (env var) skips the entire routine —
use once the calibration is trusted.

**Design notes:**

- `INTERCEPT` is used rather than `IDLE` so the priority byte matches a
  real movement command.
- Raw mm corners are sent — `MALLET_ORIGIN_PX` is not involved.  Task 1
  validates the pixel pipeline; task 2 is the physical-reach check.

---

## Known gaps / things the next agent might tackle

1. **No mid-motion preemption** -- if pysvc decides to intercept while the
   gantry is mid-IDLE-return, it has to wait. Could split cppsvc into a
   command-receiver thread + a motion-executor thread that supports
   cancellation.
2. **Critical-zone boundaries are hardcoded** -- `CRIT_TL_PX`, `CRIT_BR_PX`
   live in [`calibration_config.py`](../pysvc/calibration_config.py).  Re-run
   `crop_calibrate.py` if the camera mount changes.
3. **Rig calibration is currently off** -- the corner-assertion check
   (see *Calibration verification* above) is wired up and runs at pysvc
   startup, but the values in
   [`calibration_config.py`](../pysvc/calibration_config.py) **fail** it
   today (GANTRY-BR implies ~280 mm instead of 869 mm in X).  Someone with
   physical access to the rig needs to re-run `crop_calibrate.py` until
   both GANTRY corner lines in the PREVIEW window read OK, then paste
   the new block in.  Use `SKIP_CALIBRATION_CHECK=1` / `SKIP_CORNER_CHECK=1`
   for dev work in the meantime.
4. **`Gantry::move_to_origin()` broken on current hardware** -- per the
   *Hardware caveat* note above, cppsvc is *meant* to skip homing and
   assume the carriage is parked at `(0, 0)` mm.  At present
   [`cppsvc/main.cpp`](../cppsvc/main.cpp) still calls `g.move_to_origin()`
   and initialises `curr_x` to `DEFAULT_X_MM` (434) — so the code and the
   doc disagree.  Either guard the homing call behind a flag (e.g.
   `SKIP_HOMING=1` env or compile-time `#ifdef`) and init `curr_x/y = 0.0`,
   or document that the limit-switch fix has been completed.
5. **PUSH emit logic not yet wired** -- the workflow plan defines
   `PUSH_NORTH` / `PUSH_OUT` as two-step sequences for stationary pucks
   (see *Edge cases* above), but `main.py` currently only emits `IDLE` and
   `INTERCEPT`.  Adding the STILL-puck branches + the `ready=1` wait + the
   follow-up `target_y = 901` command is the next vision-loop task.  The
   IPC layer already supports it.  Agreed `BEHIND_OFFSET_MM = 80`
   (mallet radius ~47.5 mm + puck radius ~30 mm + slack).  If the puck
   stops being STILL between step 1 and step 2 of a sequence, abort the
   sequence and re-evaluate the state machine next tick.
6. **No watchdog** -- if pysvc crashes, cppsvc sits at its last commanded
   position.  A per-command timeout in cppsvc or a heartbeat from pysvc
   would help.
7. **Hardcoded image tags** in `cppsvc/docker-compose.yml`. A CI pipeline
   that tags images on commit and updates the compose file would help.
8. **No tests on pysvc**. The geometry helpers (`trace_path_to_bottom`,
   `first_border_intersection`, `px_to_gantry_mm`) are well-isolated and
   easy to unit-test if someone wants to add a `tests/` folder.
9. **No per-command motion profile on cppsvc** -- by design today, cppsvc
   treats every command identically (`move_to_coord` to target), and the
   "position-behind-then-shove-north" feel is encoded in the pysvc two-step
   sequence.  If we ever want a true fast/slow distinction per command
   type, the C++ side needs to branch on `cmd.command` and adjust the
   motion parameters per case.

---

## Quick file map for the next agent

| Looking for... | Look in |
| --- | --- |
| ... puck HSV / centroid (shared) | [`pysvc/green_puck_detect.py`](../pysvc/green_puck_detect.py) |
| ... how the puck is detected/tracked | [`pysvc/main.py`](../pysvc/main.py) (Kalman + `green_puck_detect`) |
| ... how trajectories are predicted | [`pysvc/main.py`](../pysvc/main.py) (`trace_path_to_bottom`, `first_border_intersection`) |
| ... when/where the gantry should move | [`pysvc/main.py`](../pysvc/main.py) (convergence-based commit section) |
| ... pixel/mm geometry or offsets | [`pysvc/calibration_config.py`](../pysvc/calibration_config.py), `px_to_gantry_mm` in [`pysvc/main.py`](../pysvc/main.py) |
| ... the TPS remap / preprocess | [`pysvc/vision_preprocess.py`](../pysvc/vision_preprocess.py), constants in [`calibration_config.py`](../pysvc/calibration_config.py) |
| ... the calibration tool | [`pysvc/crop_calibrate.py`](../pysvc/crop_calibrate.py) |
| ... visual detection test (no IPC) | [`pysvc/test_detection.py`](../pysvc/test_detection.py) |
| ... the IPC byte layout | both [`pysvc/ipc_handler.py`](../pysvc/ipc_handler.py) and [`cppsvc/include/ipc_handler.hpp`](../cppsvc/include/ipc_handler.hpp) |
| ... how the motors actually move | [`cppsvc/src/gantry.cpp`](../cppsvc/src/gantry.cpp), [`cppsvc/src/iSV57T.cpp`](../cppsvc/src/iSV57T.cpp) |
| ... what command cppsvc does on startup | [`cppsvc/main.cpp`](../cppsvc/main.cpp) |
| ... what gets deployed where | [`cppsvc/docker-compose.yml`](../cppsvc/docker-compose.yml), [`pysvc/Dockerfile`](../pysvc/Dockerfile) |

Good luck.

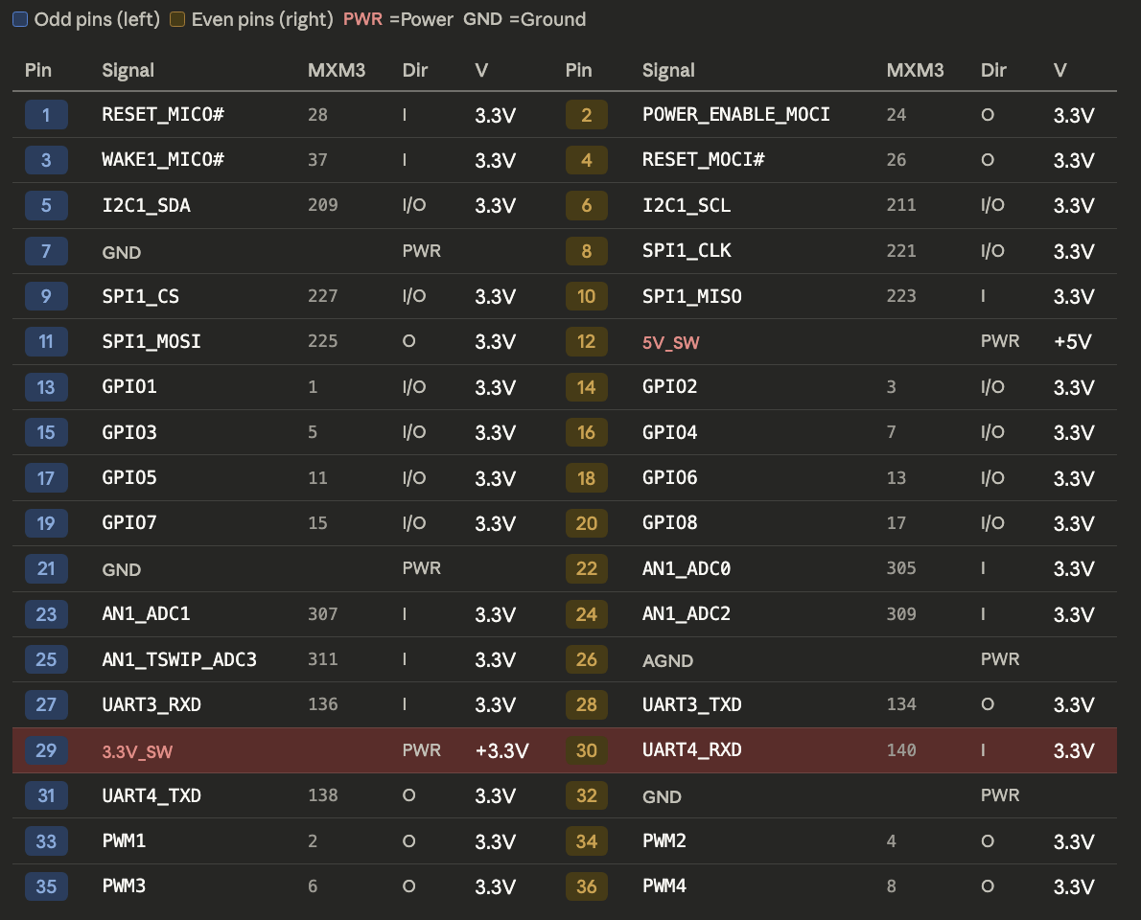
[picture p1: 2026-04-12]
docs/Ixora_X27_Pin_Map.png

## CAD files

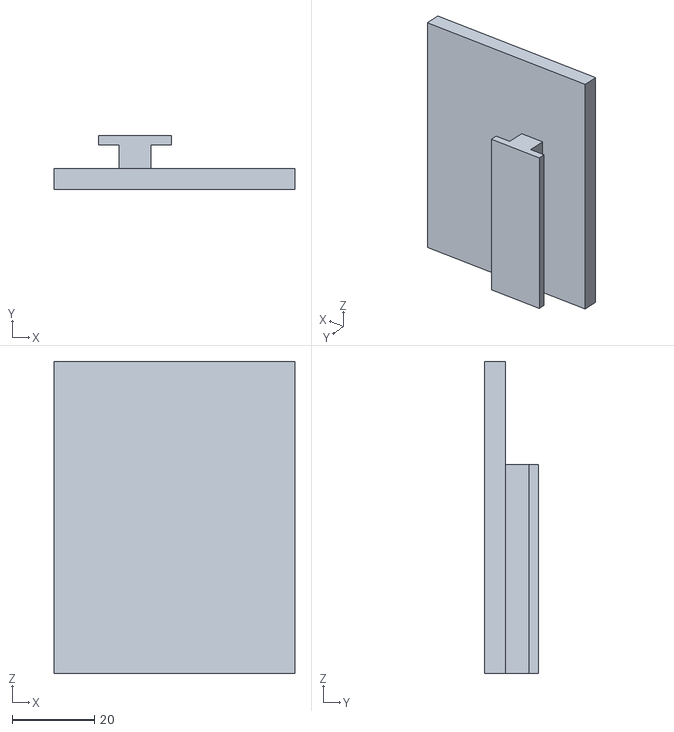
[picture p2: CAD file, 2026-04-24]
stl_designs/endblock.STL
58.5 x 13.0 x 75.8

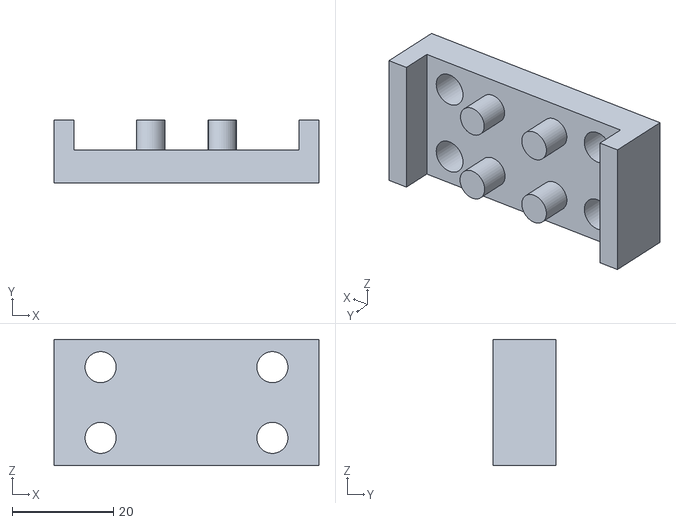
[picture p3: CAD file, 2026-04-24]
stl_designs/extend_plate.STL
52.5 x 12.5 x 25.0

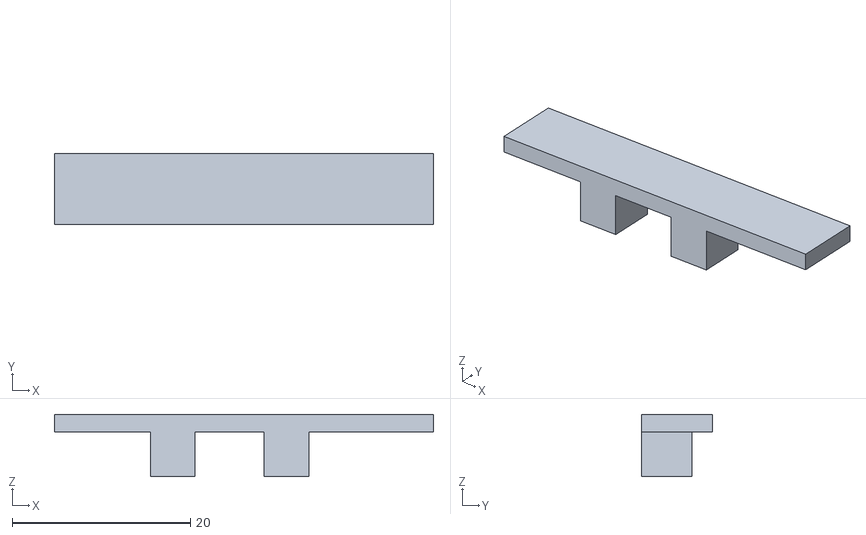
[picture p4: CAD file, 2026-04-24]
stl_designs/endblock_stopper.STL
42.5 x 8.00 x 7.00

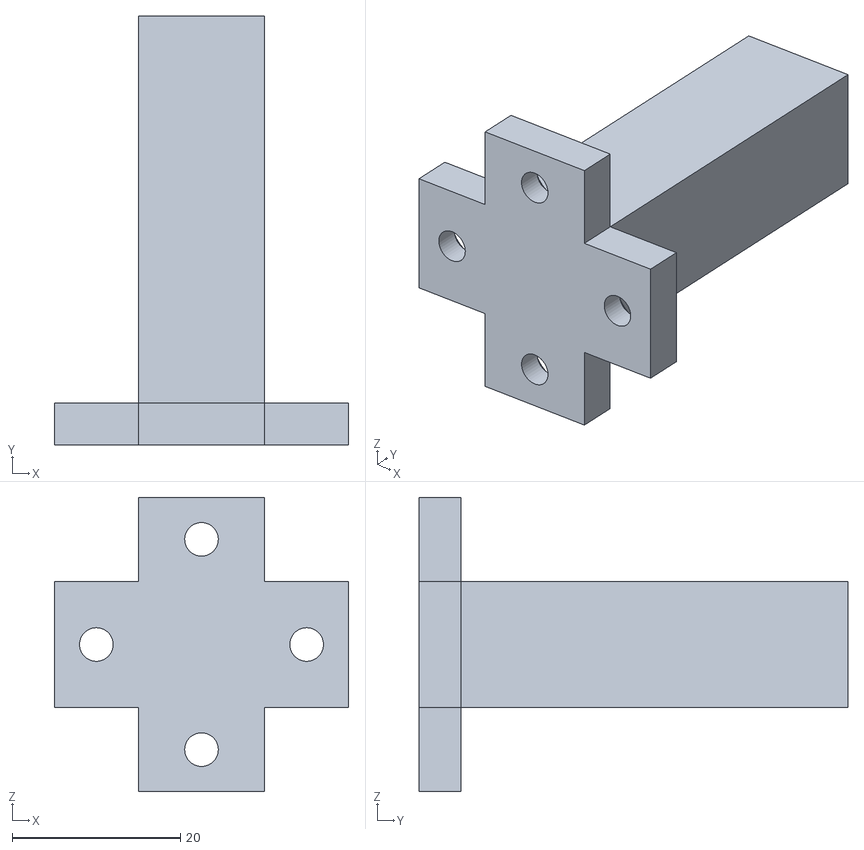
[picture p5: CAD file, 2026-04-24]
stl_designs/motor_raise.STL
35.0 x 51.0 x 35.0

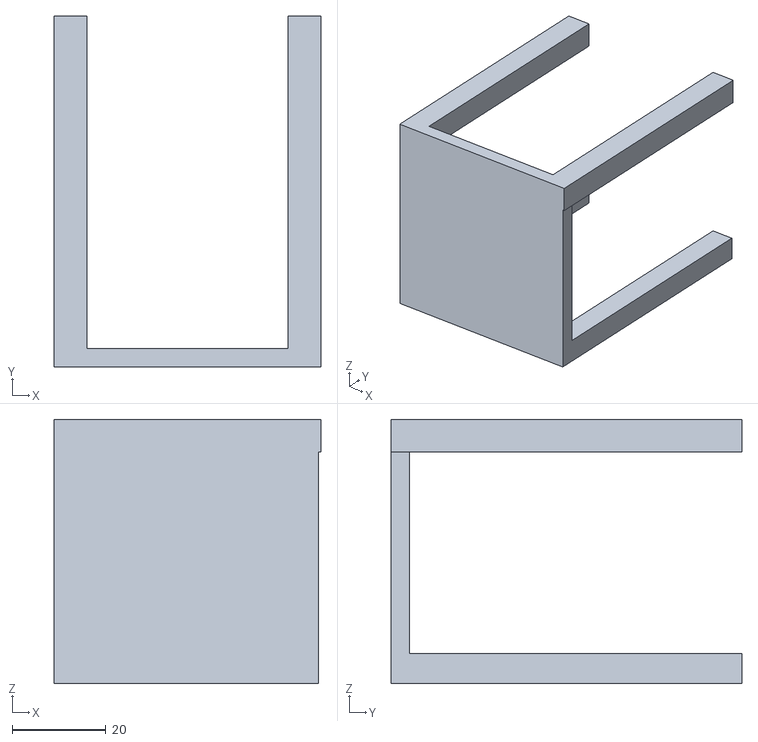
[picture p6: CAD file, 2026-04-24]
stl_designs/motor_bottom_support.STL
57.0 x 75.0 x 56.5

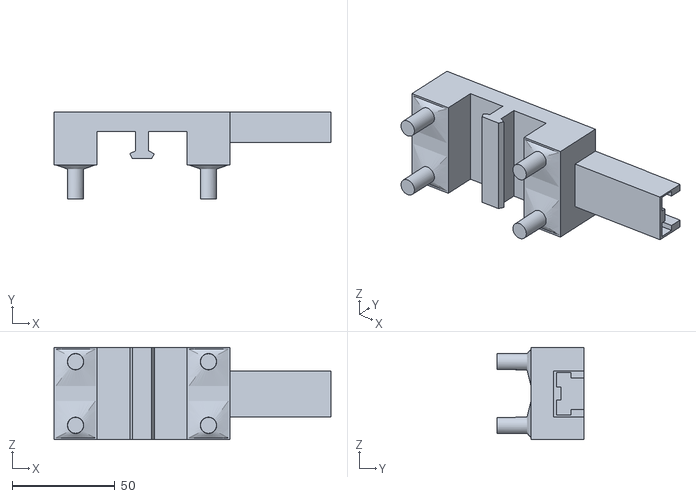
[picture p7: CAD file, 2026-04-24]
stl_designs/test_width4.STL
134.9 x 42.5 x 45.0

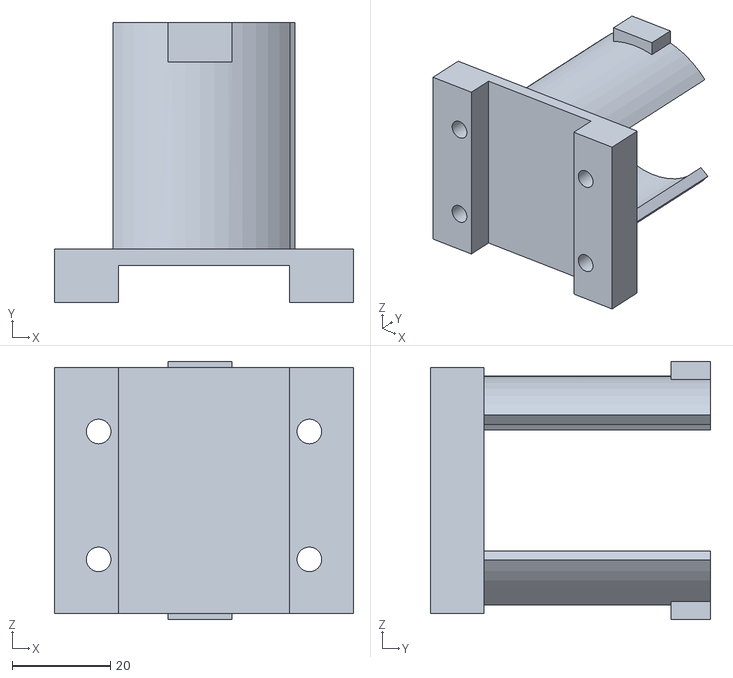
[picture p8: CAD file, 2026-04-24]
stl_designs/mallet_holder.STL
60.8 x 56.9 x 52.5

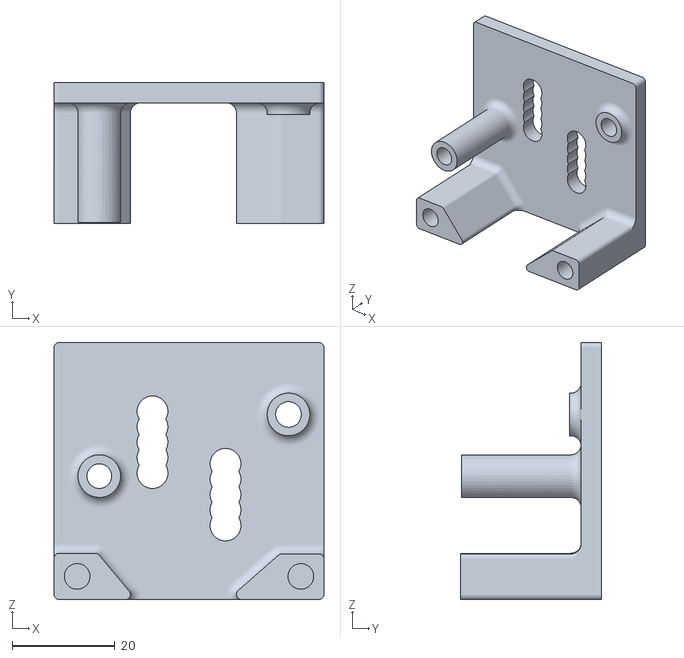
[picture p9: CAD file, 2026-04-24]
stl_designs/finals2.STL
52.5 x 27.5 x 50.0

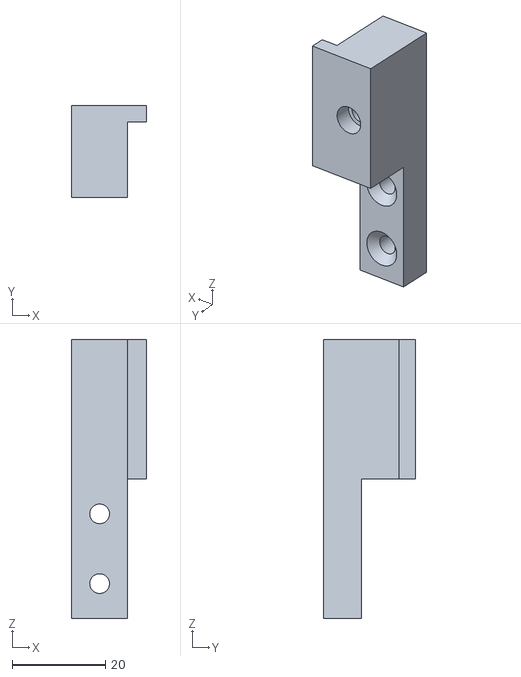
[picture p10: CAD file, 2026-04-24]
stl_designs/tst_bottom2.STL
16.0 x 19.7 x 60.0

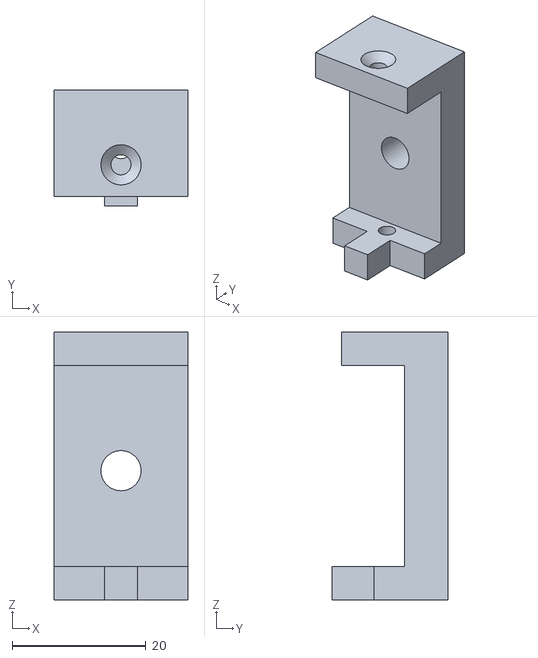
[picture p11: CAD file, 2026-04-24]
stl_designs/end_raiseholder.STL
20.0 x 17.4 x 40.0

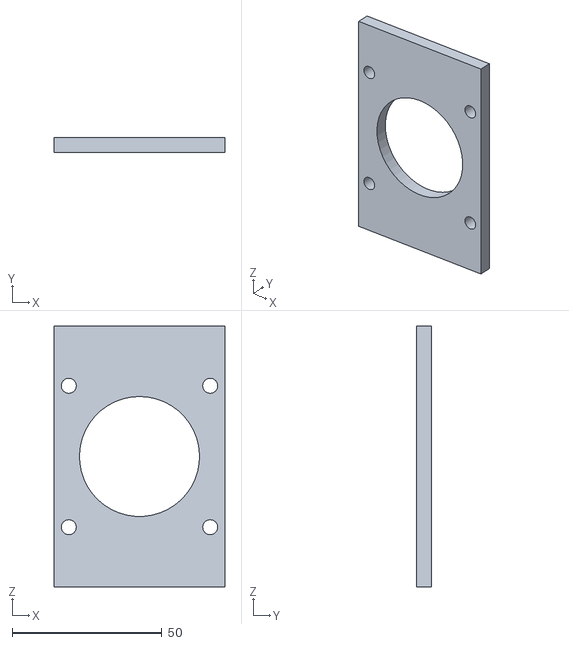
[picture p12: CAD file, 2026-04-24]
stl_designs/topfix.STL
57.0 x 5.00 x 87.0

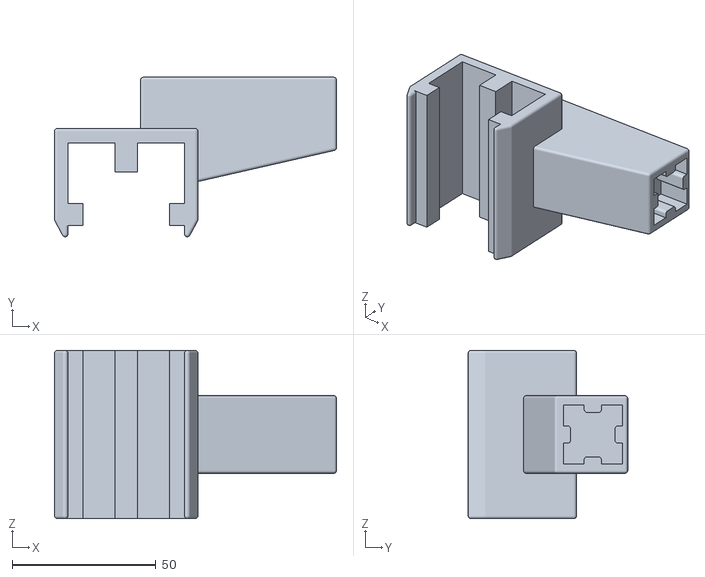
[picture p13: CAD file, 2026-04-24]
stl_designs/slider2.STL
98.3 x 55.6 x 58.7

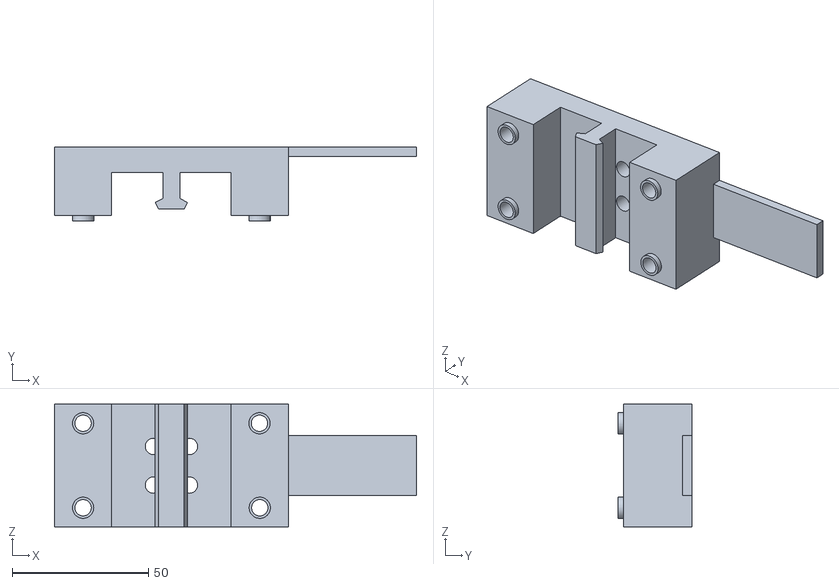
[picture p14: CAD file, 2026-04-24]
stl_designs/slidernew.STL
132.8 x 27.3 x 45.0

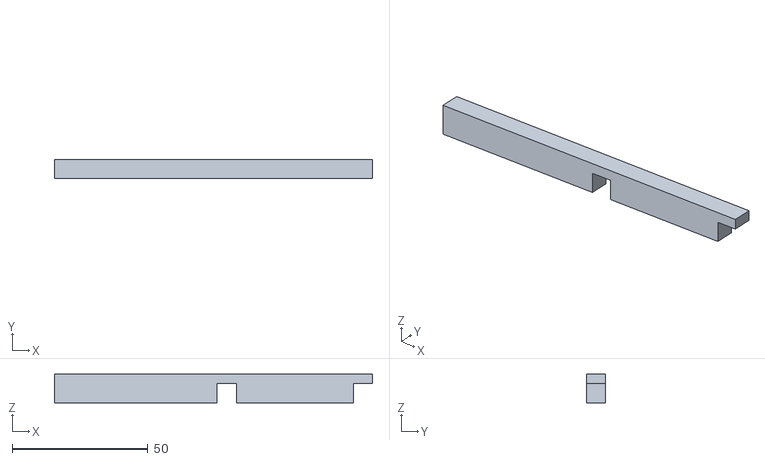
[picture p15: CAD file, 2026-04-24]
stl_designs/motor_bottom_support2.STL
117.0 x 7.00 x 10.5

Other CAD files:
stl_designs/bearingholder.STL
stl_designs/spacer.STL
stl_designs/finals1.STL
stl_designs/endingpiece1.STL
stl_designs/bearing_raise.STL
stl_designs/bottomfix.STL
stl_designs/extrusion_clamp.STL
stl_designs/final_endraise.STL
stl_designs/idler_holder.STL
stl_designs/test_top.STL
stl_designs/tst_bottom.STL

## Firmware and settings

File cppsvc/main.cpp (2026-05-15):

#include <algorithm>
#include <cerrno>
#include <csignal>
#include <cstdint>
#include <cstring>
#include <iostream>
#include <stdexcept>

#include "gantry.hpp"
#include "iSV57T.hpp"
#include "ipc_handler.hpp"
#include "limitSwitch.hpp"

// Default gantry position when idle (center-south, mm)
static constexpr unsigned DEFAULT_X_MM = 434;
static constexpr unsigned DEFAULT_Y_MM = 0;

// Graceful shutdown on SIGINT / SIGTERM
static volatile sig_atomic_t g_running = 1;
static void signal_handler(int) { g_running = 0; }

int main() {
  // ── GPIO chip handles ─────────────────────────────────────────────────────
  const char *gpio_chip4_char = "/dev/gpiochip4"; // limit switches
  const char *gpio_chip0_char = "/dev/gpiochip0"; // motors

  // Motor pin assignments
  const unsigned m1_dir_line = 8;  // Physical Pin 13
  const unsigned m1_pul_line = 9;  // Physical Pin 14
  const unsigned m2_dir_line = 12; // Physical Pin 15
  const unsigned m2_pul_line = 13; // Physical Pin 16

  // Limit switch pin assignments
  const unsigned sw1_line = 1; // Physical Pin 17
  const unsigned sw2_line = 2; // Physical Pin 18

  const uint16_t pulse_per_rev = 2000;

  gpiod_chip *chip0 = gpiod_chip_open(gpio_chip0_char);
  if (!chip0) {
    fprintf(stderr, "Failed to open %s for motor pins: %s\n", gpio_chip0_char,
            strerror(errno));
    return 1;
  }

  gpiod_chip *chip4 = gpiod_chip_open(gpio_chip4_char);
  if (!chip4) {
    fprintf(stderr, "Failed to open %s for limit switches: %s\n",
            gpio_chip4_char, strerror(errno));
    gpiod_chip_close(chip0);
    return 1;
  }

  // ── Hardware object construction ──────────────────────────────────────────
  std::cout << "Initializing limit switches...\n";
  limitSwitch sw_x(chip4, sw1_line);
  limitSwitch sw_y(chip4, sw2_line);
  std::cout << "Limit switches ready.\n";

  std::cout << "Initializing motors...\n";
  iSV57T m_lower(chip0, m1_dir_line, m1_pul_line, pulse_per_rev);
  iSV57T m_upper(chip0, m2_dir_line, m2_pul_line, pulse_per_rev);
  std::cout << "Motors ready.\n";

  std::cout << "Initializing gantry...\n";
  gantry g(m_lower, m_upper, sw_x, sw_y);
  std::cout << "Gantry ready.\n";

  // ── IPC handler ───────────────────────────────────────────────────────────
  std::cout << "Opening IPC...\n";
  IPCHandler ipc;
  std::cout << "IPC ready.\n";

  // ── Signal handlers ───────────────────────────────────────────────────────
  std::signal(SIGINT, signal_handler);
  std::signal(SIGTERM, signal_handler);

  // ── Startup sequence ──────────────────────────────────────────────────────
  std::cout << "Homing gantry...\n";
  ipc.write_status(0.0f, 0.0f, AirHockey::HOMING, 0);

  // g.move_to_origin();

  std::cout << "Homing complete.\n";

  std::cout << "Moving to default position (" << DEFAULT_X_MM << ", "
            << DEFAULT_Y_MM << ")...\n";
  g.move_to_coord(DEFAULT_X_MM, DEFAULT_Y_MM);
  ipc.write_status(static_cast<float>(DEFAULT_X_MM),
                   static_cast<float>(DEFAULT_Y_MM), AirHockey::STATE_IDLE,
                   1 // ready
  );
  std::cout << "Ready. Entering command loop.\n";

  // ── Command loop ──────────────────────────────────────────────────────────
  float curr_x = static_cast<float>(DEFAULT_X_MM);
  float curr_y = static_cast<float>(DEFAULT_Y_MM);

  while (g_running) {
    IPCHandler::CommandData cmd;
    ipc.wait_for_command(cmd);

    if (!g_running)
      break;

    std::cout << "[CMD] seq=" << cmd.seq
              << " cmd=" << static_cast<int>(cmd.command) << " target=("
              << cmd.target_x_mm << "," << cmd.target_y_mm << ")\n";

    // Signal that we are moving
    ipc.write_status(curr_x, curr_y, AirHockey::MOVING, 0);

    // Clamp target to valid gantry range
    unsigned tx = static_cast<unsigned>(
        std::clamp(static_cast<int>(cmd.target_x_mm), 0, GANTRY_X_MAX_LENGTH));
    unsigned ty = static_cast<unsigned>(
        std::clamp(static_cast<int>(cmd.target_y_mm), 0, GANTRY_Y_MAX_LENGTH));

    try {
      g.move_to_coord(tx, ty);
    } catch (const std::exception &e) {
      std::cerr << "[ERROR] move_to_coord failed: " << e.what() << "\n";
      ipc.write_status(curr_x, curr_y, AirHockey::ERROR, 0);
      continue;
    }

    curr_x = static_cast<float>(tx);
    curr_y = static_cast<float>(ty);

    ipc.write_status(curr_x, curr_y, AirHockey::STATE_IDLE, 1);
    std::cout << "[DONE] at (" << curr_x << "," << curr_y << ")\n";
  }

  std::cout << "Shutting down...\n";
  gpiod_chip_close(chip4);
  gpiod_chip_close(chip0);
  return 0;
}

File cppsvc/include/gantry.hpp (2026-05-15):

#pragma once

#include "iSV57T.hpp"
#include "limitSwitch.hpp"

#include <cstdint>

/**
 * @brief The interface for the gantry system
 */
static constexpr int GANTRY_X_MAX_LENGTH = 869; // In millimeters
static constexpr int GANTRY_Y_MAX_LENGTH = 901; // In millimeters
static constexpr int GANTRY_X_MAX_ROTATIONS =
    7925; // West-East from play side POV; Units in degrees
static constexpr int GANTRY_Y_MAX_ROTATIONS =
    8000; // North-South from play side POV; Units in degrees
static constexpr float HOMING_STEP_DEG = 10.0f;

// Trapezoidal ramp profile for move_relative.
// Adjust these constants and recompile to tune the feel of each move.
static constexpr float RAMP_BASE_RPM =
    1200.0f; // cruise RPM for the dominant motor
static constexpr float RAMP_START_RPM_FRAC =
    0.10f; // start speed as fraction of cruise RPM
static constexpr float RAMP_END_RPM_FRAC =
    0.10f; // end speed as fraction of cruise RPM
static constexpr float RAMP_UP_FRACTION =
    0.15f; // fraction of move spent ramping up
static constexpr float RAMP_DOWN_FRACTION =
    0.15f; // fraction of move spent ramping down

static constexpr float X_DEG_TO_MM =
    float(GANTRY_X_MAX_ROTATIONS) /
    float(GANTRY_X_MAX_LENGTH); // Ratio to define how many degrees to move 1
                                // millimeter in the x-axis.
static constexpr float Y_DEG_TO_MM =
    float(GANTRY_Y_MAX_ROTATIONS) /
    float(GANTRY_Y_MAX_LENGTH); // Ratio to define how many degrees to move 1
                                // millimeter in the y-axis.

class gantry {
public:
  /**
   * @brief Constructs a new (Core XY) Gantry object.
   *
   * @param p_lower_motor refers to the lower motor controlling the gantry. Pass
   * an iSV57T object.
   * @param p_upper_motor refers to the upper motor controlling the gantry. Pass
   * an iSV57T object.
   * @param p_x_origin refers to the x-axis limit switch at the origin point of
   * the gantry. Pass a limitSwitch object.
   * @param p_y_origin refers to the y-axis limit switch at the origin point of
   * the gantry. Pass a limitSwitch object.
   */
  gantry(iSV57T &p_lower_motor, iSV57T &p_upper_motor, limitSwitch &p_x_origin,
         limitSwitch &p_y_origin);

  /**
   * @brief Moves to the edges of the gantry system to see if all movement
   * functions work.
   */
  bool calibration_test();

  /**
   * @brief Moves the center of the gantry from any point it started from to
   * origin. Will use limit switches as sensors to know when coordinate 0 in
   * both axes are hit.
   */
  bool move_to_origin();

  /**
   * @brief Moves the center of the gantry system to a desired coordinate point.
   * The coordinate grid is defined in millimeters. The gantry will first
   * complete the X-axis displacement via move_x(), then the Y-axis
   * displacement via move_y(). The function will return true if the action is
   * completed. Otherwise, return false.
   *
   * NOTE: The coordinate system is in units of millimeters (mm).
   *
   * @param p_x_target is the target x-coordinate.
   * @param p_y_target is the target y-coordinate.
   */
  bool move_to_coord(unsigned p_x_target, unsigned p_y_target);

  /**
   * @brief Moves the center in the West-East direction (given the play POV) of
   * the gantry system. Takes a millimeter input and converts it to the
   * appropriate motor degrees using CoreXY mixing. After moving, the function
   * will update its current coordinates. Returns true on success.
   *
   * DETAILS: Both motors need to spin in the same direction to move in this
   * axis. Moving CLOCKWISE will move the gantry WEST. Moving COUNTER CLOCKWISE
   * will move the gantry EAST.
   *
   * @param p_mm gives the amount of millimeters the gantry system should move
   * from its current position.
   * @param p_direction tells the direction to move. A FALSE input will move the
   * center towards the EAST direction. A TRUE input will move the center
   * towards the WEST direction.
   */
  bool move_x(unsigned int p_mm, bool p_direction);

  /**
   * @brief Moves the center in the North-South direction (given the play POV)
   * of the gantry system. Takes a millimeter input and converts it to the
   * appropriate motor degrees using CoreXY mixing. After moving, the function
   * will update its current coordinates. Returns true on success.
   *
   * DETAILS: The motors need to spin in opposite directions to move in this
   * axis. Lower motor CCW + upper motor CW moves NORTH. Lower motor CW +
   * upper motor CCW moves SOUTH.
   *
   * @param p_mm gives the amount of millimeters the gantry system should move
   * from its current position.
   * @param p_direction A FALSE input will move the center towards the SOUTH
   * direction. A TRUE input will move the center towards the NORTH direction.
   */
  bool move_y(unsigned int p_mm, bool p_direction);

private:
  /**
   * @brief Runs one or both motors concurrently on separate threads. A motor
   * is skipped when its degree argument is zero. When profiled is true, uses
   * a trapezoidal velocity ramp (RAMP_* constants); otherwise rotates at the
   * motor's current constant speed. Throws std::runtime_error identifying
   * which motor failed if an exception occurs.
   *
   * @param lower_deg Degrees for the lower motor (skipped if 0).
   * @param lower_dir Direction for the lower motor (iSV57T::CW or CCW).
   * @param upper_deg Degrees for the upper motor (skipped if 0).
   * @param upper_dir Direction for the upper motor (iSV57T::CW or CCW).
   * @param profiled If true, uses rotate_profiled; if false, uses rotate.
   */
  void run_motors(float lower_deg, uint8_t lower_dir, float upper_deg,
                  uint8_t upper_dir, bool profiled);

  iSV57T &m_lower_motor;
  iSV57T &m_upper_motor;
  limitSwitch &m_x_origin;
  limitSwitch &m_y_origin;

  int curr_x = 0;
  int curr_y = 0;
};

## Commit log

2026-03-13 Initial CAD files
    - Sliding mechanism - initial ones - did not work well due to friction and a lot of resistance - (slider2)
    - added bearings that could roll on the actual extrusion instead of surface to surface sliding (test_width_4)
    - new design used cylinders that bearings would slide into and then we could put in some tape at the end to prevent bearing from sliding out. Didn't work because we ` ended up dropping the sliders and each time the cylinders would break off -
    - Endblocks - initial design to hold extrusions in place. Did not work well because the end stoppers would fly off after adding a bit extra force
    Most of this was done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
    [bearingholder.STL, endblock.STL, endblock_stopper.STL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]
2026-03-13 Working designs STL files
    New and working designs:
    slidernew - uses holes to insert screws instead of 3d printed cylinders that easily snap off, also has holes to fix the idler_holder into it
    tst_bottom/tst_bottom2 + test_top - final design to fix gantry to table stopping horizontal and vertical motion
    bottomfix + topfix - Used to help fix motor onto table using the 3d print and some sheet metal
    idlerholder - Used to hold idlers at different heights since CoreXY type of belt routing will be used
    All of this has been done since the start of the semester, since the uploading and hardware update guidelines were not totally clear I am uploading now.
    The CAD/STL files were created by Kshi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
    [bottomfix.STL, idler_holder.STL, slidernew.STL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]
2026-03-15 motor driver
2026-03-17 added the pin layout and mapping via claude and the datasheet and added the implementation files for the gantry control
    [Ixora_X27_Apalis_iMX8_GPIO_Mapping.xlsx]
2026-03-17 added switch implementation and update the motor implementation to take a gpio_chip instead of making the object in the constructor
2026-03-17 added destructors for switch and motors
2026-03-20 debugging motor stuff
2026-03-22 More CAD Files
    STL files for more parts including idler holders, mallet holders, and extender to increase width of belt route.
    [bearing_raise.STL, end_raiseholder.STL, extend_plate.STL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]
2026-04-12 added the thready thingy
2026-04-12 More STL Files
    Added STL files that are helping the belt system and hold the motors in air to match the height to the belt
    [endingpiece1.STL, extrusion_clamp.STL, motor_bottom_support.STL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]
2026-04-18 new fix ont the RPM adjustment and started on gantry interface
    [gantry.hpp, iSV57T.cpp]
2026-04-22 added prelimnary logic to gantry system and fized motor RPM logic; TODO: work on finding measurements of gantry system to hardcode
2026-04-23 added motor movement testing for kenny
2026-04-23 there is some missing stuff to do in the gantry implementation but also refine the main for everyone to read without going into the hpp file to read
    [gantry.cpp, gantry.hpp, main.cpp]
2026-04-24 moved to one folder
    [bearing_raise.STL, bearingholder.STL, bottomfix.STL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]
2026-04-24 finalized designs for the sliders as well as end raises for the belt idlers
    [final_endraise.STL, finals1.STL, finals2.STL]
2026-04-24 accidentally put it into cppsvc instead of root folder - fixed
    [bearing_raise.STL, bearingholder.STL, bottomfix.STL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]
2026-04-26 updated move coordinate function to incorporate diagonal movement. also made a calibration test function
2026-04-26 added moving at angles for motorsto support more than 45deg movement
2026-04-29 inverted the signs for x movement where moving east is no positive and west is negative. The physical origin point changed to the southwest corner from the southeast corner
    [gantry.cpp, gantry.hpp]
2026-05-05 added the fix to the diagonal function as well as the proper rotation boundaries of the gantry
    [gantry.cpp, gantry.hpp, main.cpp]
2026-05-09 removed the diagonal function in the gantry movement. Reason: causing large drifts and time to move is slower than moving in x then y
    [gantry.cpp, gantry.hpp]
